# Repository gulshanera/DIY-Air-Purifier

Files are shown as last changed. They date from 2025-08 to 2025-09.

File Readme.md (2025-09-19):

# DIY Smart Air Purifier
A low-cost **DIY Smart Air Purifier** that automatically adjusts fan speed based on real-time **PM<sub>2.5</sub>** concentration. The purifier uses a **HEPA filter** with a DC fan mounted on top and is designed to provide adaptive air cleaning for indoor environments.

This project includes both the **hardware setup** and **Arduino-based control code**, and is intended to be fully open-source for anyone to replicate or improve.

## Features
**Real-Time Monitoring** – Continuously monitors air quality using a PM<sub>2.5</sub> sensor.  
**Automatic Fan Control** – Adjusts fan speed dynamically according to PM<sub>2.5</sub> levels.  
**Energy Efficient** – Runs at lower speeds when air quality is good, saving power.  
**HEPA Filtration** – Effective particle removal for healthier indoor air.  
**Open Source** – Hardware design, circuit, and code freely available.  

## Hardware Requirements
**PM<sub>2.5</sub> Sensor** - Sensirion's SEN50 [Link](https://in.element14.com/sensirion/sen50-sdn-t/particle-sensor-dust-digital-5v/dp/3953034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)  
**HEPA Filter** - 20cm diameter, 29cm height(Standard MI air purifier Filter) [Link](https://amzn.in/d/hq0hpHi)  
**Power Supply** - 12V 2amp DC power supply [Link](https://robu.in/product/standard-12v-2a-power-supply-with-5-5mm-dc-plug-3-pin-input-plug/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)  
**DC/AC Fan** - 120mm*120mm, 12V DC Fan [Link](https://amzn.in/d/9E89Q2z)  
**Microcontroller** - Arduino Nano [Link](https://in.element14.com/arduino/a000005/arduino-nano-evaluation-board/dp/1848691)  
**Motor Driver** - L298N Motor Driver [Link](https://in.element14.com/dfrobot/dri0002/dc-motor-controller-mdv-2x2a-board/dp/3517873)  
**Display** - 0.96inch OLED display [Link](https://in.element14.com/midas/mdob128064wv-ybi/graphic-oled-cob-128-x-64pixel/dp/3565084)  

## PM sensor  
The current design supports **three Sensirion models**: **SEN50, SEN54, and SEN55**.  
All of them share the same physical footprint, making them interchangeable in this setup.  

- **SEN50** → Reports only **particulate matter (PM) values**, which are sufficient for the current application.  
- **SEN54 / SEN55** → Provide additional measurements such as **temperature, humidity, VOC, and NO<sub>x</sub>**, but come at a higher cost.  

👉 You can choose the sensor model based on the required parameters and budget.

## .9 inch vs 1.3 inch OLED Display  
**Current design files support both `0.96-inch` and `1.3-inch` OLED displays.**  
Please note that the pin locations for **`VCC`** and **`GND`** may vary depending on the display module, so always check the OLED **pinout** before connecting it to the circuit.
  

## Circuit Diagram for **2 Pin 12v DC Fan**
Both **2-pin** and **3-pin DC fans** can be used in this project.  
For controlling a 2-pin DC fan, we used an **L298N motor driver module** since it was readily available. Other methods, like MOSFET transistors, can also be used.

  

### Assembly  


## Circuit Diagram for **3 Pin PWM 12v DC Fan**  
For **3-pin PWM fans**, the **12V supply** can be connected directly to the fan while the **PWM control signal** is driven from the Arduino Nano.  
This approach simplifies the circuit design since no external motor driver is required.  

⚠️ However, PWM fans are generally **more expensive** than standard 2-pin fans, which can increase the overall cost of the project.

  

## Software and Package Required
**Arduino IDE**  
The libraries required are listed below  
- **Wire.h** (Arduino Core Component)
- **SensirionI2CSen5x.h** For controlling Sensirion Sen50 sensor [Link](https://github.com/Sensirion/arduino-i2c-sen5x)  
- **U8g2lib.h** For controlling the OLED Display [Link](https://github.com/olikraus/u8g2)
  
## Code
```
#include <Wire.h>
#include <U8g2lib.h>
#include <SensirionI2CSen5x.h>

//U8G2_SH1106_128X64_NONAME_F_HW_I2C u8g2(U8G2_R0, /* reset=*/ U8X8_PIN_NONE);      //Uncomment for 1.3 OLED
U8G2_SSD1306_128X64_VCOMH0_F_HW_I2C u8g2(U8G2_R0, /* reset=*/ U8X8_PIN_NONE);       //Uncomment for .96 OLED

SensirionI2CSen5x sen5x;

#define MOTOR_PIN 3

void setup() {
  Serial.begin(9600);
  Wire.begin();
  pinMode(MOTOR_PIN, OUTPUT);
  u8g2.begin();

  sen5x.begin(Wire);
  uint16_t error;

  error = sen5x.deviceReset();
  Serial.print("Reset: "); Serial.println(error);

  error = sen5x.startMeasurement();
  Serial.print("Start: "); Serial.println(error);

  delay(2000);
}

void loop() {
  uint16_t error;
  float mc_1p0, mc_2p5, mc_4p0, mc_10p0;
  float temp, humidity, voc, nox;

  error = sen5x.readMeasuredValues(
              mc_1p0, mc_2p5, mc_4p0, mc_10p0,
              humidity, temp, voc, nox);

  u8g2.clearBuffer();
  u8g2.setFont(u8g2_font_6x12_tf);

  if (!error) {
    u8g2.setCursor(0, 12);
    u8g2.print("PM2.5: ");
    u8g2.print(mc_2p5, 1);

    u8g2.setCursor(0, 28);
    u8g2.print("Temp: ");
    u8g2.print(temp, 1);

    u8g2.setCursor(0, 44);
    u8g2.print("RH: ");
    u8g2.print(humidity, 1);
    u8g2.print(" %");

    int pwmValue = 0;
    if (mc_2p5 <= 30) {
      pwmValue = 100;
    } else if (mc_2p5 <= 100) {
      pwmValue = 200;
    } else {
      pwmValue = 255;
    }
    
    analogWrite(MOTOR_PIN, pwmValue);
    float fanspeed=(pwmValue/255.0)*100.0;
    u8g2.setCursor(0, 60);
    u8g2.print("Fan Speed: ");
    u8g2.print(fanspeed,1);
    u8g2.print(" %");

  } else {
    u8g2.setCursor(0, 30);
    u8g2.print("Sensor Err ");
    u8g2.print(error);
    analogWrite(MOTOR_PIN, 0);
  }
  
  drawSmiley(mc_2p5);
  u8g2.sendBuffer();
  delay(1000);
}

void drawSmiley(int pm25) {
  int x = 100;   // X position (top-right)
  int y = 20;    // Y position
  int r = 16;    // face radius

  // Face outline
  u8g2.drawCircle(x, y, r, U8G2_DRAW_ALL);

  // Eyes
  u8g2.drawDisc(x-6, y-5, 2);
  u8g2.drawDisc(x+6, y-5, 2);

  // Mouth based on PM2.5
if (pm25 <= 30) {
  // 😀 big smile
  u8g2.drawArc(x, y+3, 6, 125, 260);
} else if (pm25 <= 60) {
  // 🙂 small smile
  u8g2.drawArc(x, y+3, 6, 140, 240);
} else if (pm25 <= 90) {
  // 😐 flat
  u8g2.drawLine(x-6, y+5, x+6, y+5);
} else if (pm25 <= 120) {
  // 🙁 small frown
  u8g2.drawArc(x, y+8, 6, 280, 100);
} else if (pm25 <= 250) {
  // 😣 big frown
  u8g2.drawArc(x, y+8, 6, 250, 130);
} else {
  // 😷 mask
  u8g2.drawBox(x-8, y+2, 16, 10);
  u8g2.drawLine(x-8, y+2, x-14, y);
  u8g2.drawLine(x+8, y+2, x+14, y);
}

}

```
## Setup Instruction
**Hardware Setup Instruction**
- For a beginner, I recommend testing each component one by one before assembling the entire circuit.
- Pull-up resistor is compulsory in Arduino nano for I2C communication [Video](https://www.youtube.com/watch?v=Z1_Ag3dxH34&t=75s), [Website](https://www.totalphase.com/blog/2024/07/what-are-i2c-pull-up-resistors-calculate-their-values/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)
- For the entire circuit, including the 12V DC motor, power is provided by a 12V DC adapter. Please be careful with the connection. Don't fry the nano.
- Test the entire circuit before going for the final assembly.

## 3D Printed Parts and Assembly Guidelines
**3D Parts**  
There are 3 parts in the model. **Top(Cover)**, **Middle(Hardware mounting)**, and the **Bottom part(Hepa Mount)**


The top cover includes a slot for the OLED display, which can be secured on the designated pads using M2 screws (1–2 screws are sufficient). The other components—such as the SEN50 PM<sub>2.5</sub> sensor, L298N motor driver, Arduino Nano, and fan—should be installed at the positions indicated below.  

While installing, make sure the top cover matches the holes created for the SEN50 sensor and the landing legs on the cover match with holes on the middle part. Lastly, the bottom HEPA filter cover should be added to the middle part by the M2 screw through the allocated holes.

oshw_facts

Guess what? This project is certified by Open Source Hardware Association 🙂


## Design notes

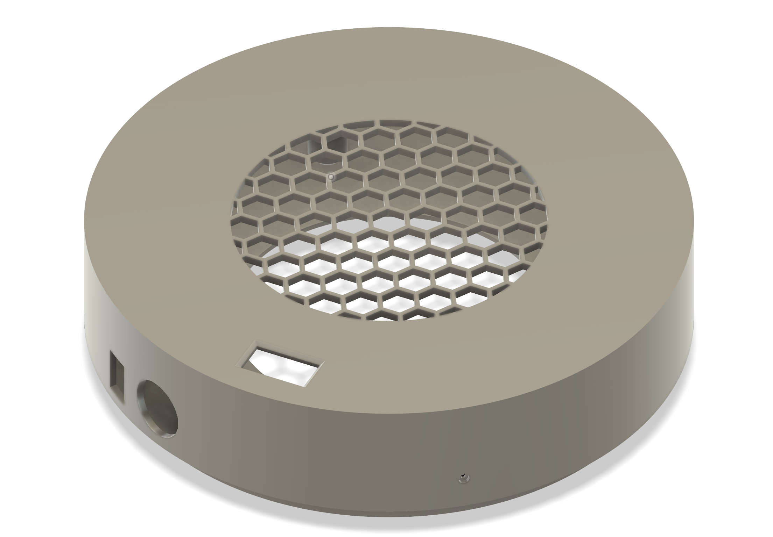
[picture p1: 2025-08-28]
Image/Screenshot 2025-08-28 152737.png

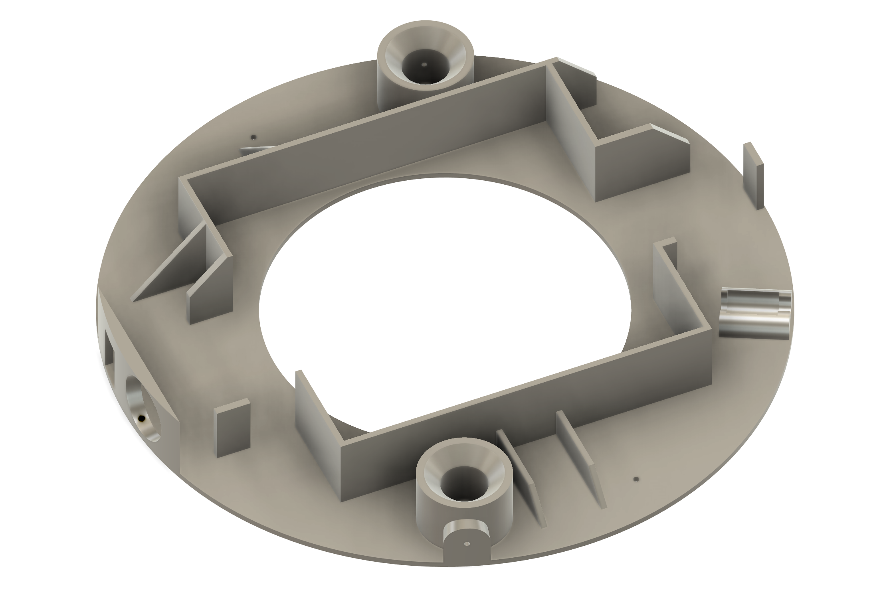
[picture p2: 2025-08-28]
Image/Screenshot 2025-08-28 152844.png

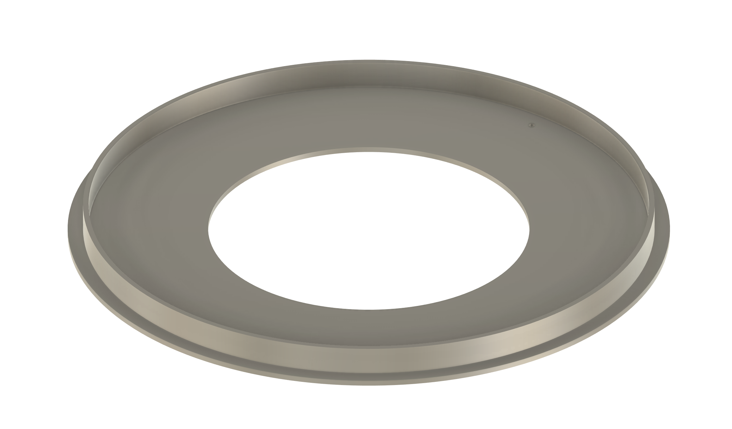
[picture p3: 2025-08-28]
Image/Screenshot 2025-08-28 152825.png

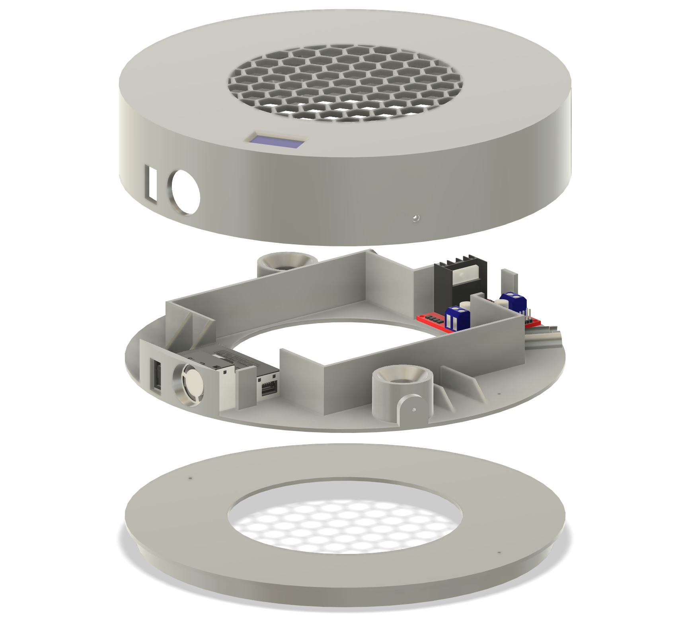
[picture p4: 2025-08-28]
Image/Screenshot 2025-08-28 153240.png

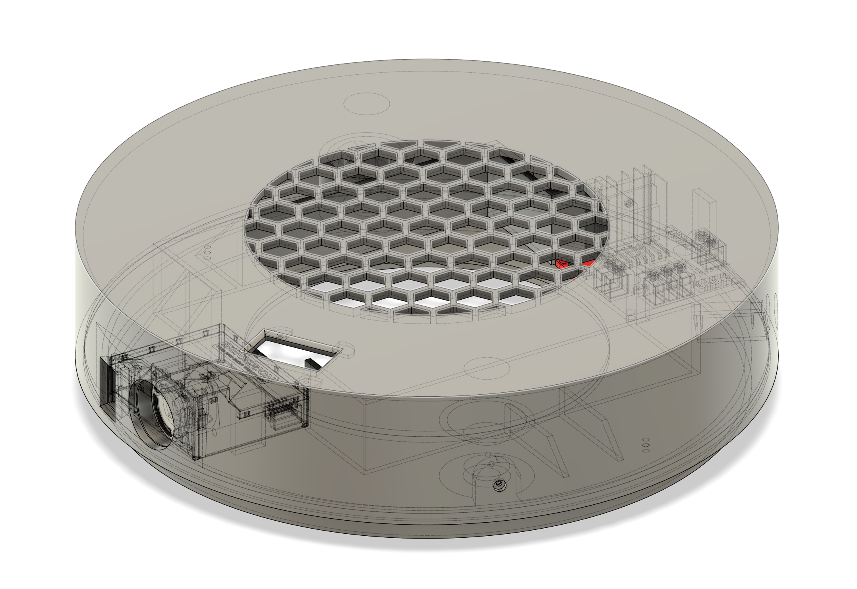
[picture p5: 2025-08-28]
Image/Screenshot 2025-08-28 153029.png

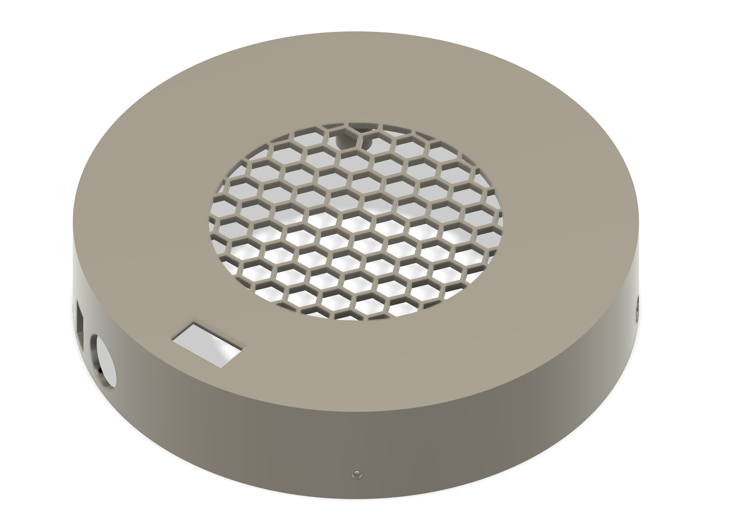
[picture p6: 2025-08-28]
Image/Screenshot 2025-08-28 152436.png

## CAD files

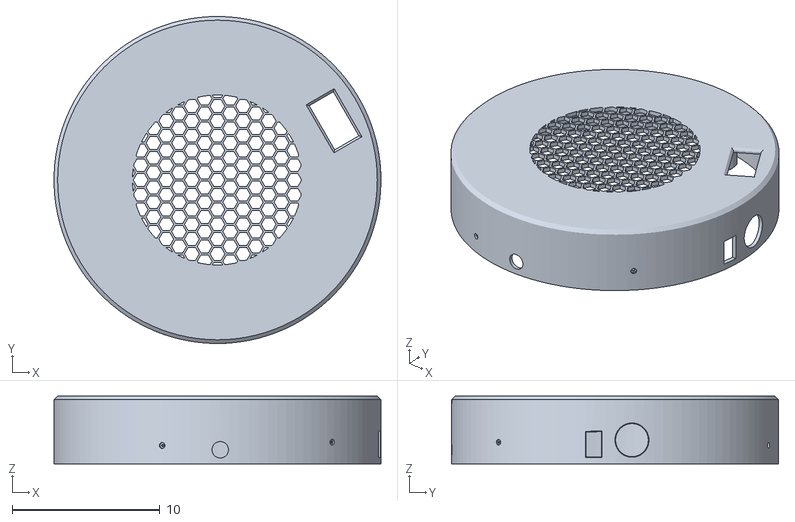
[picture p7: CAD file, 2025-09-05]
CAD_Model/Air purifier Top 0.96 oled.stl
22.1 x 22.1 x 4.60

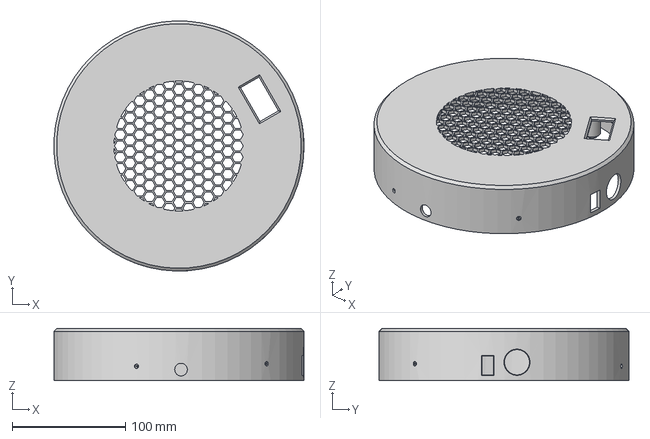
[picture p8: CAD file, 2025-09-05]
CAD_Model/Air purifier Top 1.3 oled.step
221.1 x 221.3 x 46.0 mm

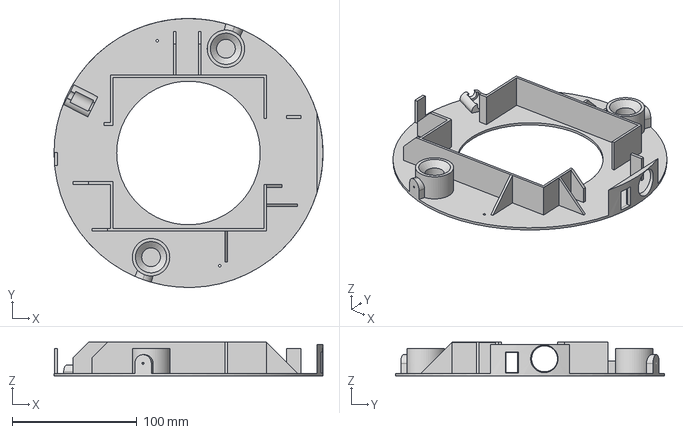
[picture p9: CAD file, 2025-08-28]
CAD_Model/Air purifier Middle.step
215.5 x 215.4 x 27.0 mm

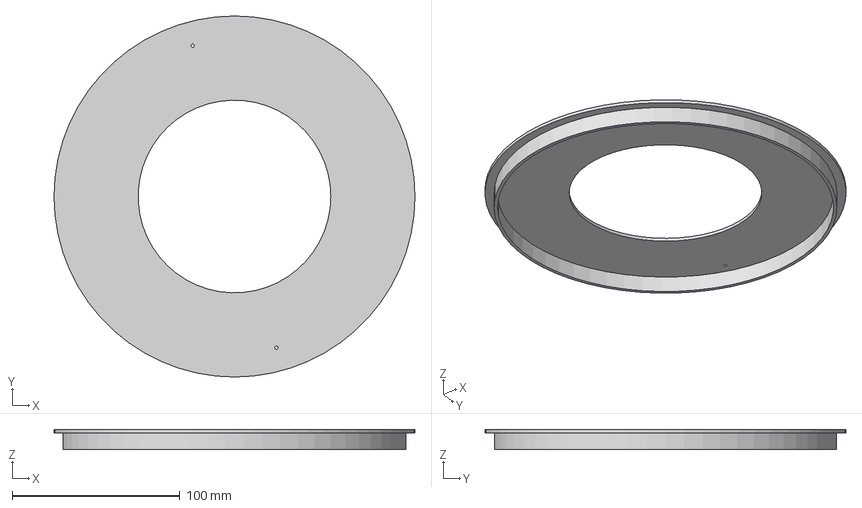
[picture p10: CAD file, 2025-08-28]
CAD_Model/Air purifier Bottom.step
215.5 x 215.5 x 12.0 mm

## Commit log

2025-09-05 Delete CAD_Model/Air purifier Top.step
    Removing Old version
    [Air purifier Top.step]
2025-09-05 Added different top part for varying OLED size
    [Air purifier Top 0.96 oled.stl, Air purifier Top 1.3 oled.step]
